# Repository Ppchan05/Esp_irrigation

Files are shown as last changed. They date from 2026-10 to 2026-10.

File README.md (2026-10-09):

Discrete PD & duty cycles for ESP32 automated small-scale irrigation

This project compares threshold-based irrigation control against discrete PD with optimized duty cycles to reduce water consumption.

LINKS: <br>
Summary: [Google Drive](https://drive.google.com/file/d/11pVFdfzkQdqfgXTPnlWxrb4dMgaT-5HM/view?usp=sharing)<br>
Full Document: [Google Drive](https://drive.google.com/file/d/1opUbFz7Rgay45Kw-4ME0JdJNk1bW7KVy/view?usp=sharing) <br>
Performance demonstration: [Google Drive](https://drive.google.com/file/d/1UBHNy69AnGAdbu0q8fOJZ9K0pUszHvJz/view?usp=sharing) <br>

SYSTEM ARCHITECTURE:<br>
Modeling: OpenModelica<br>
Microcontroller: ESP32 (Arduino framework / C++)<br>
Sensors & Actuators: LM393 soil moisture resistive probe, 3-6V submerged pump<br>
Circuit Design: Darlington pair transistor switch designed in KiCad<br>
Control Theory: Discrete PD controller tuned using FODT simulations<br>
Communication: Publishing data via Adafruit MQTT before entering deep-sleep mode<br>

RESULTS:<br>
Threshold baseline: ~8.8% moisture overshoot<br>
PD control (second iteration): 3% moisture overshoot<br>
Efficiency: ~8% reduction in water consumption per cycle  <br>

REPOSITORY STRUCTURE: <br>
```text
├──Software/
│       └──Main/
│             └──main.ino    # Main ESP32 firmware with control logic & deep-sleep
├──Models/
│       ├──FOPDTparameters.mo    # First-Order Plus Dead-Time model of plant  
│       ├──PID system.mo    # PID and PD closed loops
│       ├──SoilModel.mo    # Soil block
│       └──Threshold system.mo    # Threshold closed loop
└──Hardware/
        ├──Datasheets/    # Datasheets for circuit transistors
        │          ├──2N2222.pdf
        │          └──2sd1207.pdf
        └──Schematic/
                   ├──System interconnections.kicad_sch    # KiCAD schematic file
                   └──System interconnections.pdf    # High resolution exported file

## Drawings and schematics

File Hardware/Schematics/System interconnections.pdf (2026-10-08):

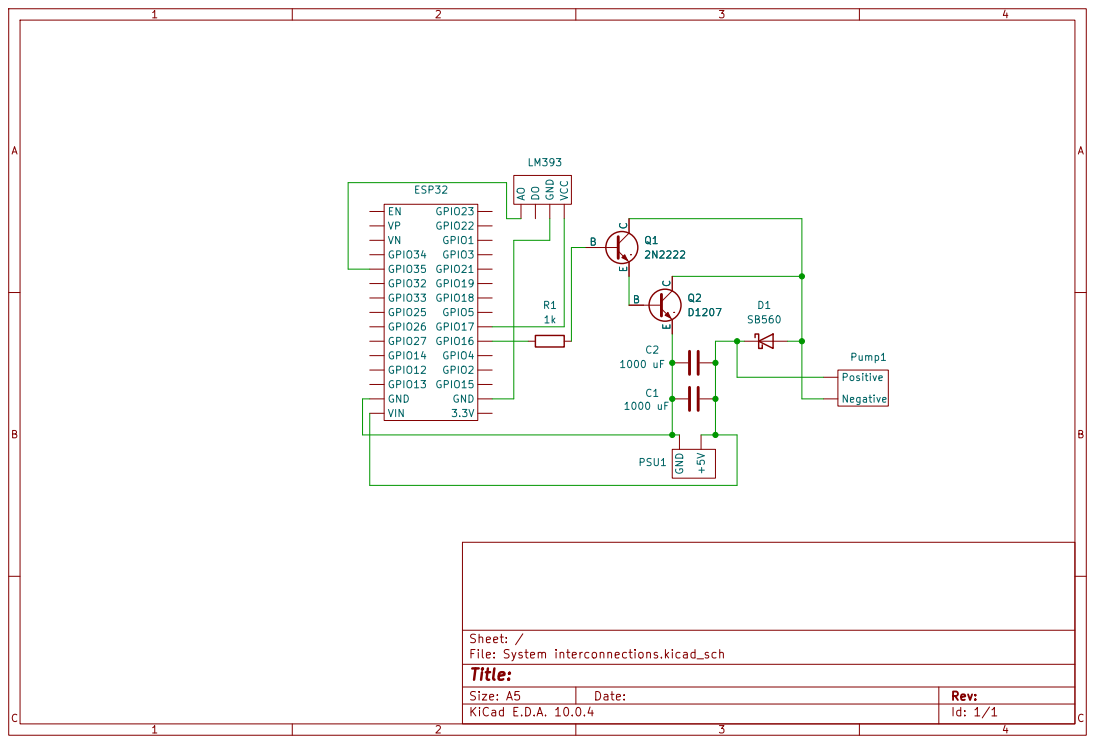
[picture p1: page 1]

Size: A5 | Rev: | C Date:
KiCad E.D.A. 10.0.4 | Id: 1/1

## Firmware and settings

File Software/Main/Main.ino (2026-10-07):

#include <WiFi.h>
#include <Adafruit_MQTT.h>
#include <Adafruit_MQTT_Client.h>
#include <OpenWeatherMap.h>

//WiFi connection settings
const char* WIFI_NAME = "WIFI_SSID";
const char* WIFI_PASSWORD = "WIFI_PASSWORD";
WiFiClient client;

//Adafruit mqtt connection setings
#define AIO_SERVER  "io.adafruit.com"
#define AIO_SERVERPORT  1883
#define AIO_USERNAME  "AIO_USERNAME"
#define AIO_KEY "AIO_KEY"
Adafruit_MQTT_Client mqtt(&client, AIO_SERVER, AIO_SERVERPORT, AIO_USERNAME, AIO_KEY);
Adafruit_MQTT_Publish temp = Adafruit_MQTT_Publish(&mqtt, "AIO_USERNAME/feeds/temp");
Adafruit_MQTT_Publish hum = Adafruit_MQTT_Publish(&mqtt, "AIO_USERNAME/feeds/hum");
Adafruit_MQTT_Publish mess = Adafruit_MQTT_Publish(&mqtt, "AIO_USERNAME/feeds/messages");

//OpenWeather settings
OpenWeatherMap weather;
const char* CITY = "Kyiv";
const char* COUNTRY = "UA";
const char* API_KEY = "OPENWEATHERMAP_API_KEY";
OWM_Forecast forecast;

//Pinout for physical connections
const byte SOIL_SUPPLY_PIN = 17;
const byte SOIL_DATA_PIN = 35;
const byte PUMP_PIN = 16;

//Soil sensor's calibratiing readings
const int WET_VALUE = 700;
const int DRY_VALUE = 4095;

//Data variables
int humData = 0;
const byte UPPER_THRESHOLD = 70;
const byte LOWER_THRESHOLD = 30;
const byte SAFETY_MARGIN = 10; //Safety margin value for max error calculation
double averageTemp = 0;
const unsigned long long hours = 3600000000ULL; //One hour in microseconds
const unsigned long DUTY_LENGTH = 60000; //Length of duty cycle in miliseconds
const unsigned long PUMP_MAX_WORKING_TIME = 5000; //Maximum pump working time
const unsigned long DUTY_CYCLE_LENGTH = 120000; //Length of the duty cycle

//Soil measuring function
void readSoilMoisture(){
  digitalWrite(SOIL_SUPPLY_PIN, HIGH);
  delay(1000);
  humData = analogRead(SOIL_DATA_PIN);
  digitalWrite(SOIL_SUPPLY_PIN, LOW);
  humData = map(humData, DRY_VALUE, WET_VALUE, 0, 100);
  humData = constrain(humData, 0, 100);
  hum.publish((uint32_t)humData);
  return;
}

//PD controller function
void discretePDControl(int& humData){
  //initializing of datatypes for variables
  double Kp = 0.214;
  double Td = 0.472;
  double MaxRawOutput = 0;
  double rawPDoutput = 0;
  double mappedPDoutput = 0;
  unsigned long  pumpWorkingTime = 0;
  unsigned long waitingTime = 0;
  int CurrentError = 0;
  int PrevError = 0;
  int maxError = 0;
  unsigned long time = 0;
  //Error calculations
  CurrentError = UPPER_THRESHOLD - humData;
  PrevError = CurrentError;
  maxError = UPPER_THRESHOLD - LOWER_THRESHOLD+SAFETY_MARGIN;
  MaxRawOutput = Kp * maxError; 
  //Duty cycle
  int c = 1;
  for(;CurrentError > 0;){
    //Mapping controller output, calculating pump work and waiting time 
    rawPDoutput = Kp * (CurrentError + Td * (CurrentError-PrevError));
    mappedPDoutput =  (rawPDoutput/MaxRawOutput);
    mappedPDoutput = constrain(mappedPDoutput, 0.2 ,1);
    mess.publish("PD output:");
    mess.publish(mappedPDoutput*5);
    mess.publish("seconds of pump working time");
    pumpWorkingTime = PUMP_MAX_WORKING_TIME * mappedPDoutput;
    time = millis();
    //turning ON pump for a calculated time
    digitalWrite(PUMP_PIN, HIGH);
    while((millis() - time) < pumpWorkingTime){
      
    }
    digitalWrite(PUMP_PIN, LOW);
    waitingTime = DUTY_CYCLE_LENGTH - pumpWorkingTime;
    delay(waitingTime);
    //Taking measurments of soil after watering
    PrevError = CurrentError;
    readSoilMoisture();
    //Calculating new error
    CurrentError = UPPER_THRESHOLD - humData;
    mess.publish("Cycle №");
    mess.publish((uint32_t)c);
    c++;
  };
  return;
}

//Average temp for 24hours using Open Weather Map forecast
void getAverageTemp(){
  mess.publish("Getting temperature forecast");
  weather.getForecastByCity(CITY, COUNTRY, &forecast, 8);
  double summ = 0;
  int i = 0;
  for (;i < forecast.cnt; i++){
    summ += forecast.items[i].main.temp;
  }
  if(i == 0){
    mess.publish("weather function error");
  } 
  else{
    averageTemp = summ/i;
    temp.publish(averageTemp);
  }
}

//Soil humidity prediction based on temp data. Func calculates hours of deep sleep and puts board in it.
void prediction(double CurrentH){
  getAverageTemp();
  if (averageTemp == 0){
    mess.publish("Skipping prediction");
  }
  mess.publish("Predicting soil evaporation");
  int c = 0;
  double Ke = 0.0123;
  while (CurrentH > (LOWER_THRESHOLD)){
    CurrentH = CurrentH -averageTemp * Ke; //Soil humidity formula
    c++;
  }
  //If calculated time is less then 24h, then call PD function. Esle exit function
  if(c<24){
    discretePDControl(humData);
    mess.publish("Sleeping for 24h");
    delay(1000);
    esp_sleep_enable_timer_wakeup(24ULL*hours);
    esp_deep_sleep_start();
  }
  else{
   return;
  }
}

//WiFi connection check fucnction. If board can't connect to WiFi for 30seconds - restart the ESP
void checkWiFi(){
  if(WiFi.status() == WL_CONNECTED) return;
  WiFi.disconnect(true, true);
  WiFi.begin(WIFI_NAME, WIFI_PASSWORD);
  int retry = 0;
  while (WiFi.status() != WL_CONNECTED && retry < 30){
    delay(1000);
    retry++;
  }
  if(WiFi.status() != WL_CONNECTED) {
    ESP.restart();
  }
}

//Adafruit connection function. If not connected, reconect attempt every 3seconds for 90seconds.
void conectMQTT(){
  int8_t server_respond;
  if(mqtt.connected()) return;
  int retry = 0;
  while((server_respond = mqtt.connect()) != 0 && retry < 30){
    mqtt.disconnect();
    delay(3000);
  }
  if(server_respond != 0){
    ESP.restart();
  }
}

//Initialization, MQTT connection, control execution and deep-sleep entry
void setup() {
  Serial.begin(9600);
  //Pin modes initialization and making sure they are off
  pinMode(SOIL_SUPPLY_PIN, OUTPUT);
  pinMode(PUMP_PIN, OUTPUT);
  digitalWrite(SOIL_SUPPLY_PIN, LOW);
  digitalWrite(PUMP_PIN, LOW);
  //Caling WiFi and mqtt connection functions 
  checkWiFi();
  conectMQTT();
  //Initializing weather library
  weather.begin(API_KEY);
  weather.setUnits(OWM_UNITS_METRIC);
  weather.setLanguage("en");

  //logic execution and deep-sleep
  delay(100); //startup delay
  readSoilMoisture();
  if (humData > (LOWER_THRESHOLD)){
    prediction(humData);
    mess.publish("Sleeping for 24h");
    delay(1000);
    esp_sleep_enable_timer_wakeup(24ULL*hours);
    esp_deep_sleep_start();
  }
  else{
    discretePDControl(humData);
    mess.publish("Sleeping for 24h");
    delay(1000);
    esp_sleep_enable_timer_wakeup(24ULL*hours);
    esp_deep_sleep_start();
  }
}


void loop() {

}
